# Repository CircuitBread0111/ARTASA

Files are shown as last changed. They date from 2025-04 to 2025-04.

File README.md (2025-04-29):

# ARTASA: Automated Robotic Text And Speech Assistant

**Author:** Jerrin C. Redmon  
**Platform:** Raspberry Pi + ESP32  
**Date:** April 15, 2025  

## 🧾 Abstract 

ARTASA, a handheld robotic vision system, is designed to assist individuals who have difficulty reading due to blindness, dyslexia, or other vision impairments. Many people with these conditions struggle to determine whether an object contains text. ARTASA addresses these challenges by processing the environment, detecting and interpreting text, and then converting it into speech using text-to-speech software.

The system utilizes a dedicated Serial Peripheral Interface (SPI) camera module designed to capture images at an optimal resolution and color balance, ensuring efficient processing by the Optical Character Recognition (OCR) system. A Raspberry Pi is employed as a dedicated computer to manage the overall software, enhancing both the speed and accuracy of the process. The system operates through three primary stages: image acquisition, image and text processing, and audio output. For optimal performance, it identifies text with a confidence level of 75% or higher before reading it aloud.

The simple handheld device makes it easy to automatically scan objects, identify and verbalize text. This allows for a compact and adaptable design that can be deployed in various environments.

### 🔧 ARTASA Hardware Unit
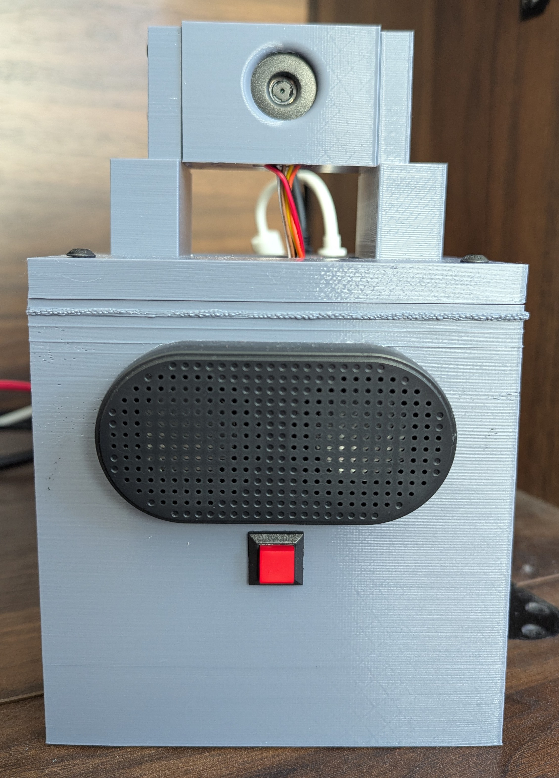
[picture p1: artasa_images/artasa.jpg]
ARTASA Hardware


---
## 📖 Features
- **Button-triggered OCR pipeline**
- **Speech feedback at every stage**
- **On-boot readiness via systemd service**
- **Real-time communication with an ESP32 camera module over UART**

---

## 🧠 Project Structure

| File | Description |
|---|---|
| `artasa.service` | Systemd service to run `artasa_boot.py` on startup |
| `artasa_boot.py` | Startup script that announces readiness and waits for a button press |
| `artasa_main.py` | Main logic: captures image, runs OCR, and speaks the detected text |
| `artasa_camera.ino` | Arduino/ESP32 sketch that captures a JPEG image upon receiving a command |

---

## 🖥️ Software Requirements

- **Python 3.8+**
- **PaddleOCR**
- **OpenCV**
- **Piper TTS** (local text-to-speech engine)
- **gpiozero** (for button input)
- **Systemd** (for auto-start on boot)
- **Arducam_Mega**

Install dependencies with:

```bash
pip install paddleocr opencv-python gpiozero
```

Make sure Piper is installed and accessible at:  
`/home/artasa/.local/bin/piper`

---

## 🔧 Hardware Requirements

- Raspberry Pi (tested on Raspberry Pi 5)
- Arducam Mega 5MP SPI camera module
- Push button wired to **GPIO16**
- Speaker (supports `aplay` for audio output)

---

## 🔁 Boot Flow

1. `artasa.service` triggers `artasa_boot.py` on boot.
2. `artasa_boot.py` plays a startup greeting via Piper.
3. Waits for a button press on GPIO16.
4. When pressed, it runs `artasa_main.py`.

---

## ▶️ Main OCR Flow (`artasa_main.py`)
### 🧠 OCR Text Detection Example
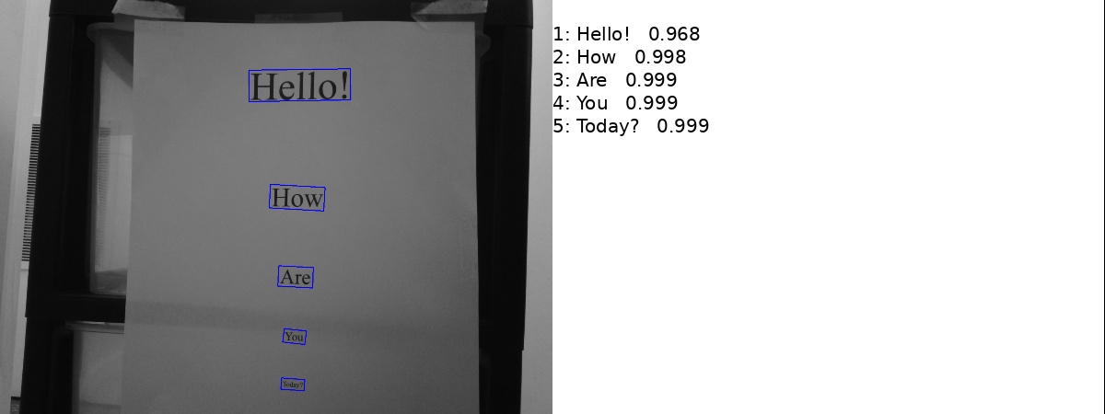
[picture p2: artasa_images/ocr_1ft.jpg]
OCR Output Example


- Sends `"CAP"` to ESP32 via serial (`/dev/ttyUSB0`, 921600 baud).
- Receives a JPEG image over serial (detects SOI `0xFFD8` and EOI `0xFFD9` markers).
- Saves image as `image_output.jpg`.
- Runs PaddleOCR and filters text with confidence > **75%**.
- Saves extracted text to `ocr_output.txt`.
- Uses Piper TTS to read out the result.

---

## 📷 ESP32 Firmware (`artasa_camera.ino`)

- Listens for `"CAP"` command over serial.
- Captures and sends image in JPEG format.
- Appends `"DONE"` to indicate completion.

---

## 🔊 Text-to-Speech Function

Both `artasa_boot.py` and `artasa_main.py` use the `say()` function:

```python
subprocess.Popen([
  "piper", "--model", MODEL_PATH,
  "--config", CONFIG_PATH,
  "--output_file", OUTPUT_WAV
], stdin=subprocess.PIPE)
```

This creates and plays a `.wav` file using `aplay`.

---

## 🧠 Systemd Setup

### 1. Install the Service

```bash
sudo cp artasa.service /etc/systemd/system/
sudo systemctl daemon-reexec
sudo systemctl enable artasa.service
sudo systemctl start artasa.service
```

### 2. File Contents (Excerpt)

```ini
[Unit]
Description=ARTASA Boot Service

[Service]
WorkingDirectory=/home/artasa/Desktop/artasa_master
ExecStart=/usr/bin/env python3 /home/artasa/Desktop/artasa_master/artasa_boot.py
Restart=always
User=artasa
Group=artasa

[Install]
WantedBy=multi-user.target
```

---

## 🚀 Running Manually (Debugging)

If needed, you can run the programs directly:

```bash
python3 artasa_boot.py  # For startup behavior and button handling
python3 artasa_main.py  # To manually run the OCR and speech pipeline
```

---

## 🛠️ Future Improvements

- Add multilingual OCR and speech options.
- Improve serial communication robustness with checksums.
- Add audio feedback for OCR errors or low confidence.

---

### ⚙️ Hardware-Software Interaction Diagram
System Diagram 2

## 📄 License

MIT License.  
Designed and built by **Jerrin C. Redmon**.

---

## 🧠 Acknowledgments

- [PaddleOCR](https://github.com/PaddlePaddle/PaddleOCR)
- [Piper TTS](https://github.com/rhasspy/piper)
- [OpenCV](https://opencv.org/)
- [Arducam](https://github.com/ArduCAM/Arducam_Mega)
- Raspberry Pi + ESP32 communities

---

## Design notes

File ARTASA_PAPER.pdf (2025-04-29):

# Automated Robotic Text and Speech Assistant

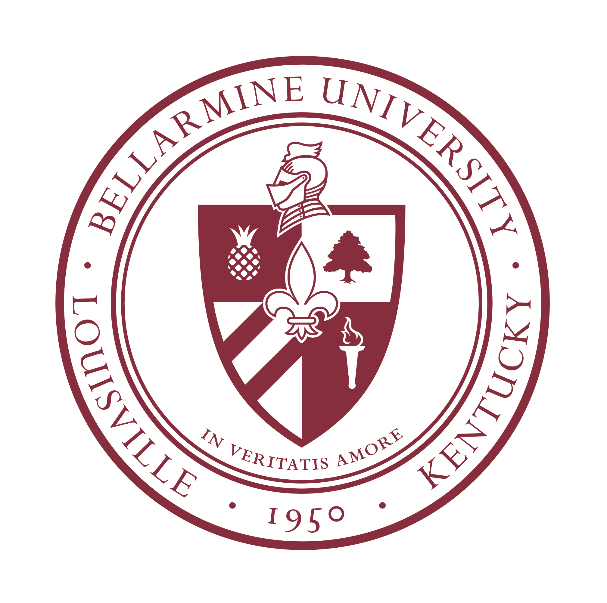
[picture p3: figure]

# Jerrin C. Redmon

# April 29, 2025

Bellarmine University: 2001 Newburg Rd, Louisville, KY 40205

_____________________________________________________________________________________________

ABSTRACT: ARTASA, a handheld robotic vision system, is designed to assist individuals who have difficulty reading due to blindness, dyslexia, or other vision impairments. Many people with these conditions struggle to determine whether an object contains text. ARTASA addresses these challenges by processing the environment, detecting and interpreting text, and then converting it into speech using text-to-speech software. The system utilizes a dedicated Serial Peripheral Interface (SPI) camera module designed to capture images at an optimal resolution and color balance, ensuring efficient processing by the Optical Character Recognition (OCR) system. A Raspberry Pi is employed as a dedicated computer to manage the overall software, enhancing both the speed and accuracy of the process. The system operates through three primary stages: image acquisition, image and text processing, and audio output. For optimal performance, it identifies text with a confidence level of 75% or higher before reading it aloud. The simple handheld device makes it easy to automatically scan objects, identify and verbalize text. This allows for a compact and adaptable design that can be deployed in various environments.

_____________________________________________________________________________________________

### 1. Introduction

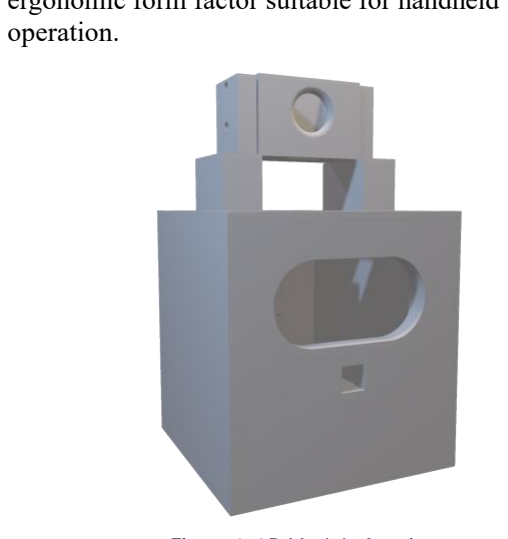
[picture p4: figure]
operation.

Access to printed text remains a significant barrier
for people with visual or cognitive impairments. Traditional assistive tools can be expensive or overly complex, limiting accessibility. ARTASA addresses this by providing an intuitive, embedded system capable of capturing text in real-time and converting it into clear speech output. It simplifies the user interaction to a single button press and automates all backend processes.

### 2. System Overview

The ARTASA system is composed of four primary components that work together to provide real-time text recognition and speech output. At the core of image acquisition is an ESP32 microcontroller paired with an Arducam Mega 5MP camera, which captures images upon button activation. These images are transmitted via serial communication to a Raspberry Pi 5, which handles the processing pipeline. The Raspberry Pi utilizes PaddleOCR, a deep learning-based optical character recognition engine, to extract text from the received images. Once the text is recognized, it is vocalized using Piper TTS, a lightweight, offline-capable text-to-speech engine, enabling immediate auditory feedback to the user.

### 3. Design and Hardware

The hardware configuration of the ARTASA system includes several integrated components designed for efficient image capture and user interaction. At the forefront is the ESP32 module equipped with an Arducam Mega 5MP camera, which serves as the primary imaging device. A tactile button, wired directly to the Raspberry Pi 5 running Pi OS, allows users to manually trigger image capture. Audio output is facilitated by an 8-ohm speaker connected to the Pi, enabling clear verbal feedback. All components are housed within a custom 3D-printed enclosure (see Figure 1), providing a compact and ergonomic form factor suitable for handheld

### 3.1 Software Workflow

The software workflow of the ARTASA system is designed to efficiently process and vocalize textual information from captured images. The sequence begins with a user-initiated trigger event, where a button press activates the system. Upon activation, the ESP32 captures a JPEG image using the Arducam Mega 5MP camera. This image is then transmitted to Raspberry Pi via USB serial communication. Once received, the Raspberry Pi processes the image using PaddleOCR, a deep learning-based engine that extracts text. To ensure reliability, only text with a confidence score of 75% or higher is retained. Finally, the filtered text is vocalized through Piper TTS, which converts the recognized content into speech and outputs it through the connected speaker. A systemd .service file (artasa.service) was configured to run the Python OCR-to-speech script on startup. This ensures ARTASA operates autonomously after power-up.

Figure 1: 3D Model of casing

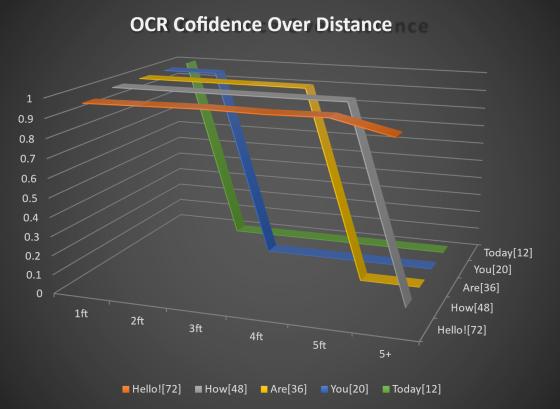
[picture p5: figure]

### 3.2 Electrical Schematic

This schematic, designed in KiCad, demonstrates the physical wiring and logic levels for interfacing the Arducam module with the ESP32 UART pins. It includes decoupling, buzzer output for feedback, and clearly labeled GPIO usage, ensuring repeatable set up.

The full wiring schematic of ARTASA includes:

- An ESP32 wired to an Arducam module and Buzzer
- USB serial communication lines connecting to the Raspberry Pi
- Button connection between Raspberry Pi GPIO pins

### 4. Testing and Results

Testing was conducted using a vertically arranged sentence printed on paper, viewed at increasing distances. Confidence scores from PaddleOCR were recorded, (see Figure 3). OCR Confidence over Distance illustrates the performance and limitations of the ARTASA system’s text recognition capabilities at varying distances. On average, the latency from image capture to speech output is approximately 2.5 seconds. The system is capable of reading fonts as small as 10 points under favorable lighting conditions, maintaining an accuracy range of 85–95% for high-contrast text. The implemented OCR confidence filter effectively eliminates low-quality reads, enhancing the reliability of spoken output. However, system performance diminishes significantly at distances beyond four feet. Additionally, motion blur and suboptimal lighting conditions adversely affect OCR confidence, underscoring the importance of stable positioning and adequate illumination during use.

### 5. Conclusion and Future Work

ARTASA successfully demonstrates a functional, self-contained assistive reading system for visually impaired users. Its offline operation, simple interface, and modular architecture make it a compelling tool for real-world use. Future enhancements could include:

- Adding feedback to indicate OCR success/failure
- Incorporating translation support
- Deploying a higher-resolution camera module
- Building a custom ergonomic enclosure with tactile feedback

References

[1] PaddleOCR, PaddleOCR: Optical Character Recognition with PaddlePaddle. [Online]. Available: https://github.com/PaddlePaddle/PaddleOCR
[2] Piper TTS, Piper: A fast, local neural text-tospeech system. [Online]. Available: https://github.com/rhasspy/piper
[3] Espressif Systems, ESP32-S3-DevKitC Hardware Reference. [Online]. Available: https://docs.espressif.com/projects/espidf/en/latest/esp32/api-reference/index.html (https://docs.espressif.com/projects/esp-idf/en/latest/esp32/api-reference/index.html)
[4] Arducam, Arducam Mega 5MP OV5642 SPI Camera Module for Any Microcontroller. [Online]. Available: https://docs.arducam.com/Arduino-SPIcamera/MEGA-SPI/MEGA-SPI-Camera/ (https://docs.arducam.com/Arduino-SPI-camera/MEGA-SPI/MEGA-SPI-Camera/)

Figure 3: Graph of OCR Confidence

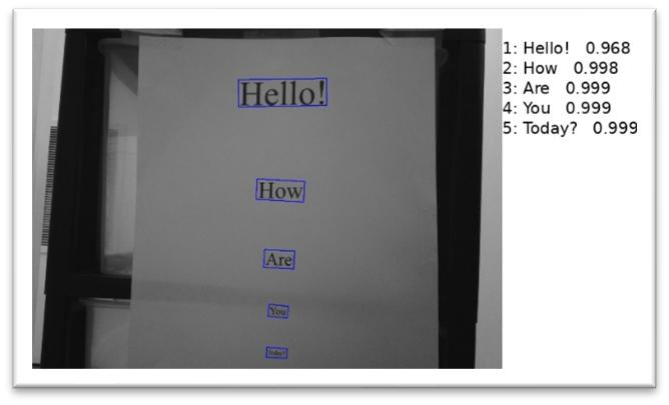
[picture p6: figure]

Figure 2: Image of OCR output

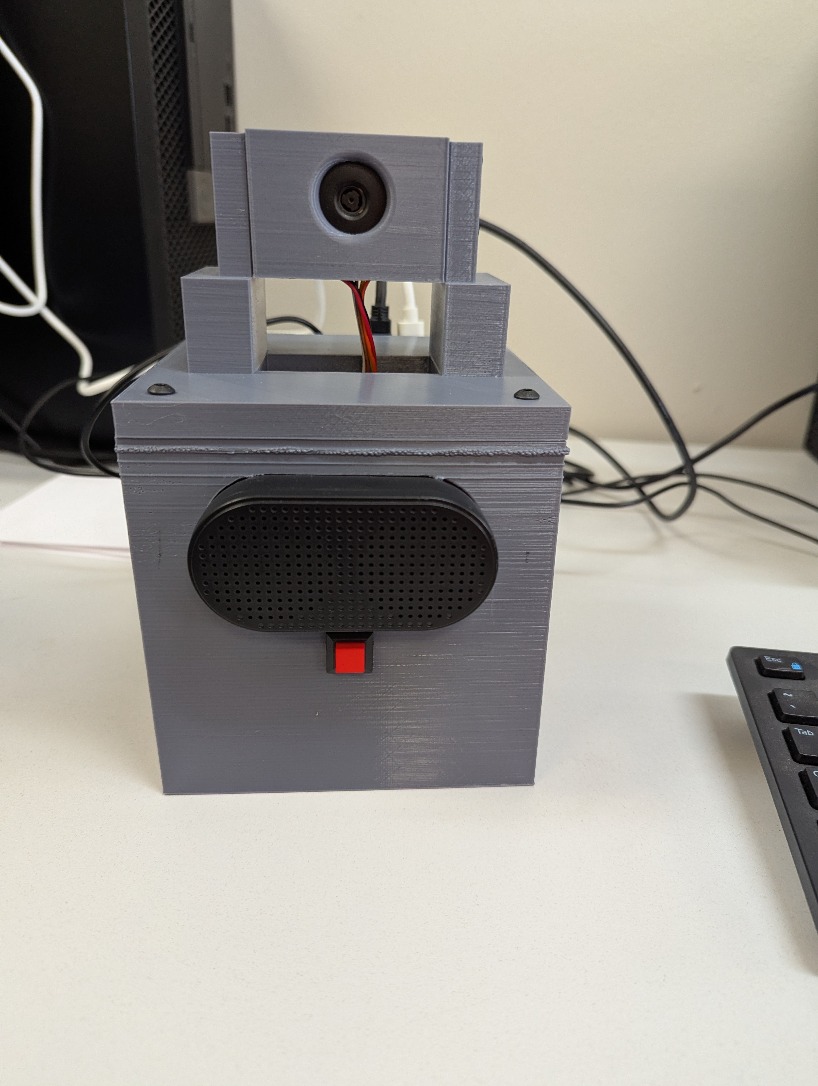
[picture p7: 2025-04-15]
artasa_images/artasa2.jpg

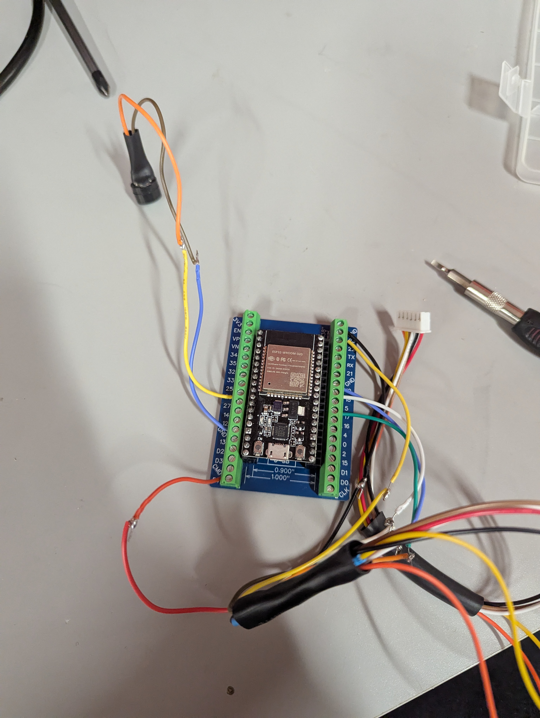
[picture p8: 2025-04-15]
artasa_images/image_mcu.jpg

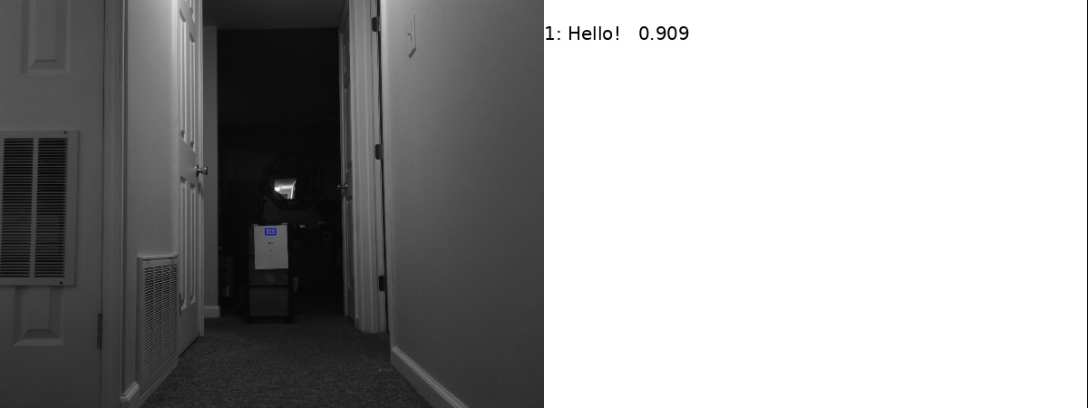
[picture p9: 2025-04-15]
artasa_images/ocr_5ft+.jpg

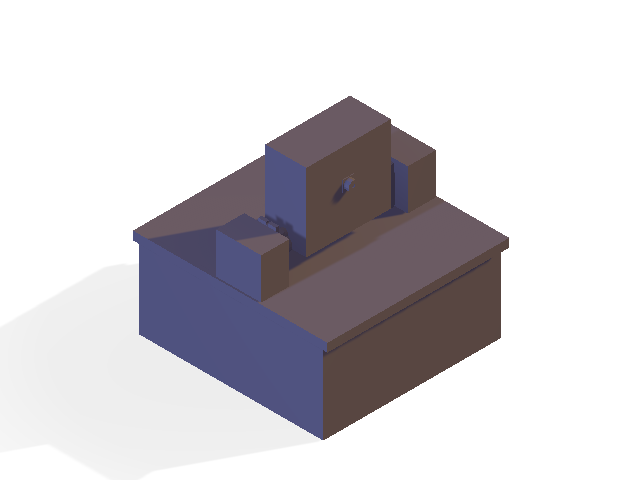
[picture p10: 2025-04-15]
artasa_images/ARTASA_Model_A.png

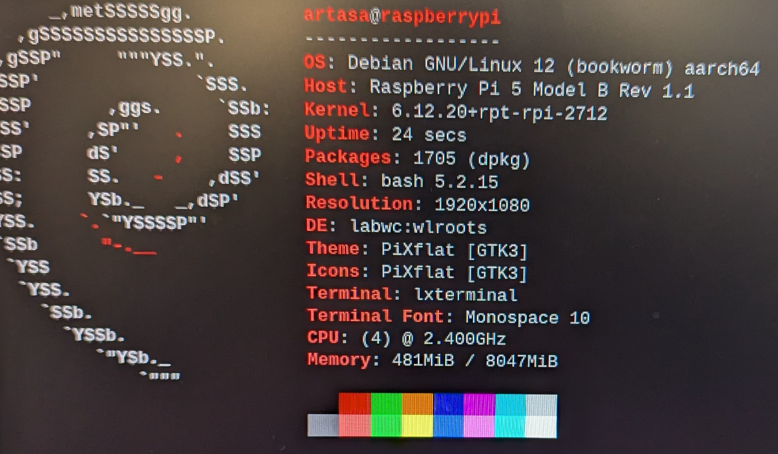
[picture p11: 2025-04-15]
artasa_images/neofetch.jpg

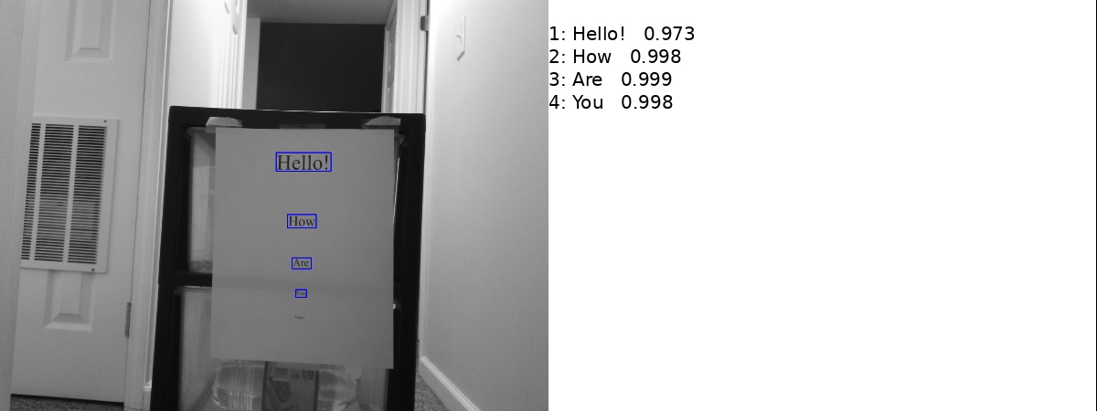
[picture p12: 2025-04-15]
artasa_images/ocr_2ft.jpg

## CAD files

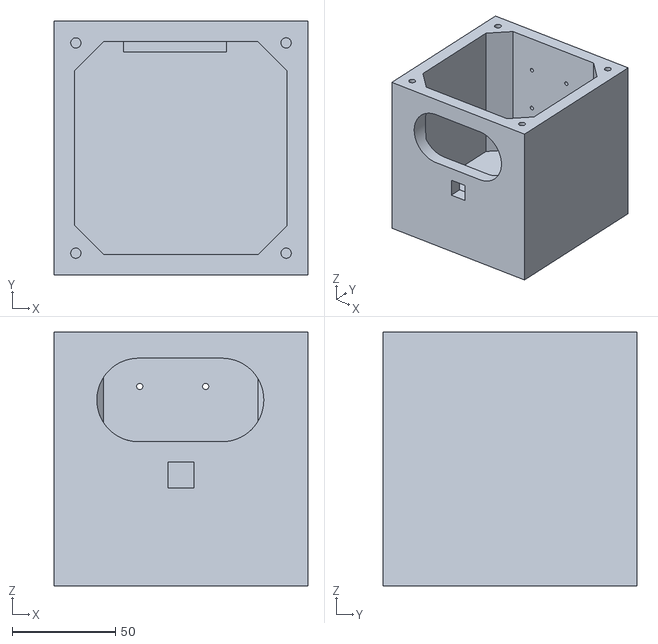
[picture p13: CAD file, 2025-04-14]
artasa_models/BOX.stl
123.3 x 123.3 x 123.3

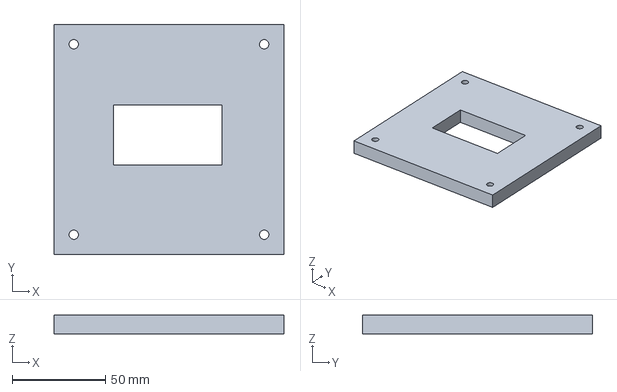
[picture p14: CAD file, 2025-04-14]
artasa_models/CAD_files/top.FCStd
123.3 x 123.3 x 10.0 mm

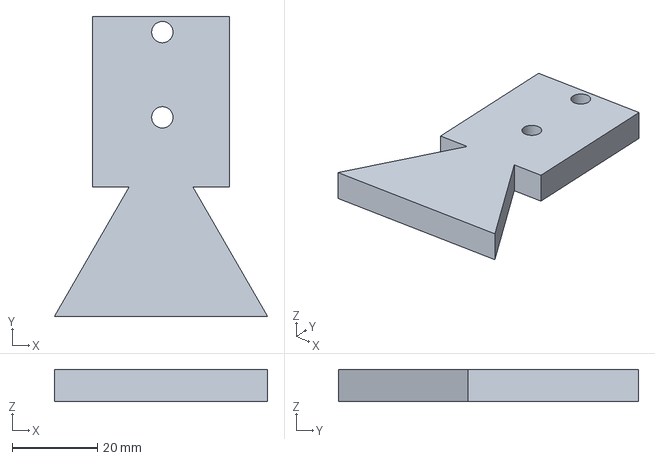
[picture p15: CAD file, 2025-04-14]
artasa_models/CAD_files/Camera_Bracket.FCStd
50.0 x 70.3 x 7.50 mm

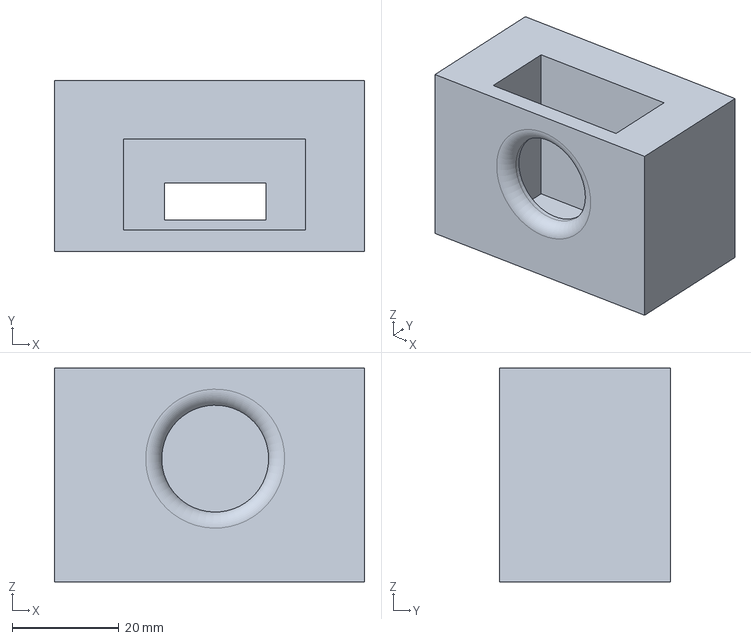
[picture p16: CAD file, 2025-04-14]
artasa_models/CAD_files/Camera_Base.FCStd
58.0 x 32.0 x 40.0 mm

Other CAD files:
artasa_models/CAD_files/body.FCStd
artasa_models/Camera_Base.stl
artasa_models/Top.stl

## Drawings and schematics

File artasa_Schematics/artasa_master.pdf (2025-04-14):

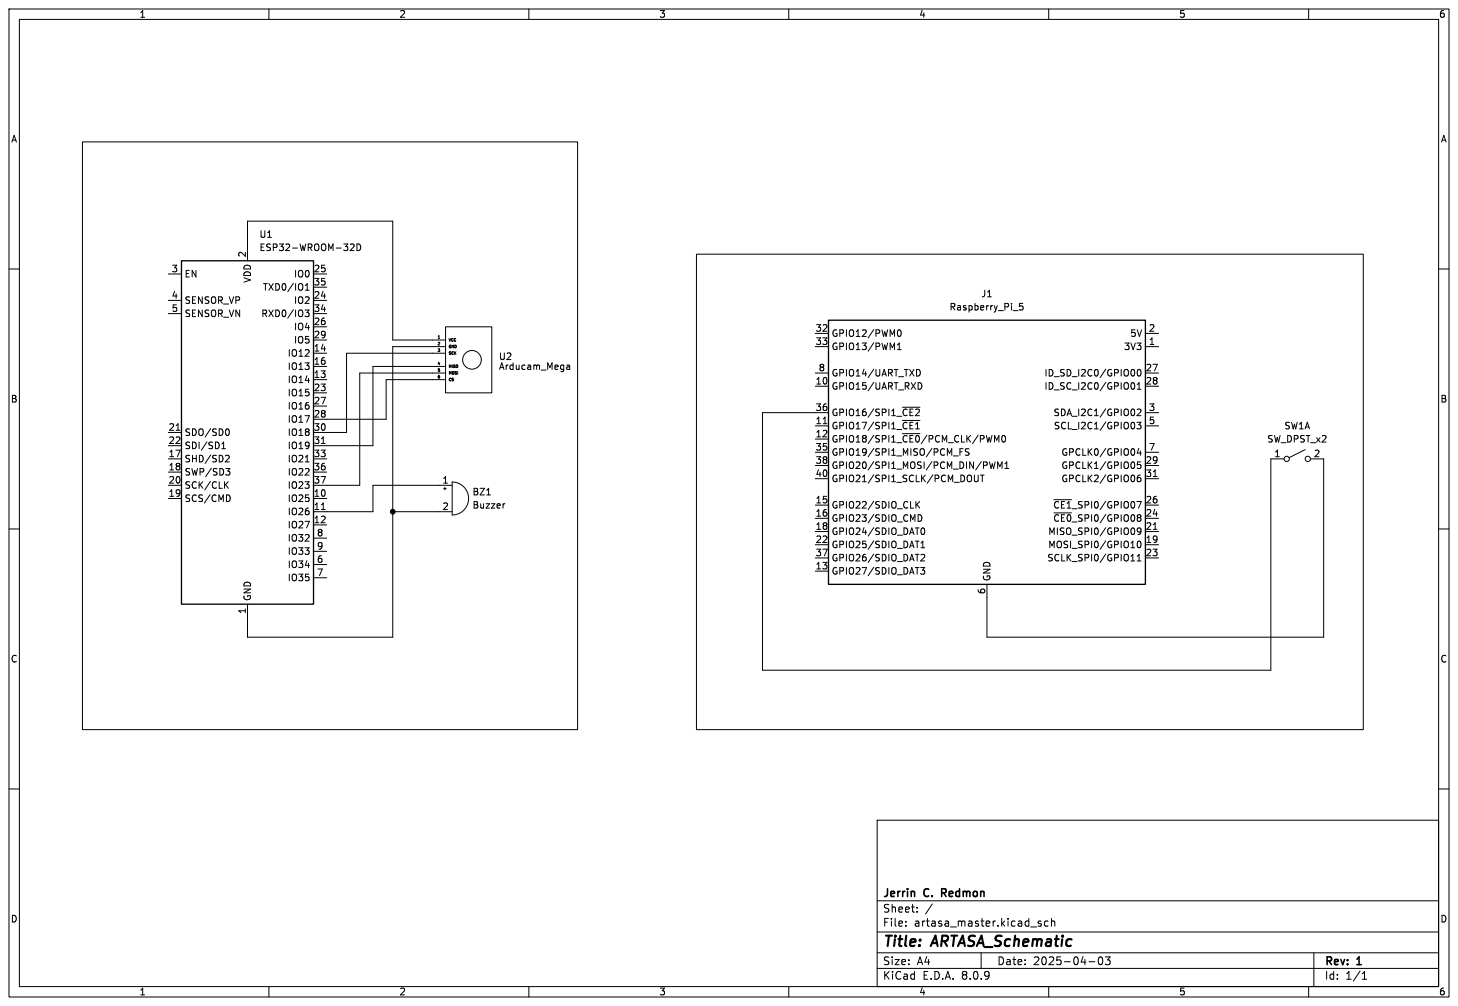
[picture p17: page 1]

2 SCK/CLK 20 SDO/SD0 21 SDI/SD1 22

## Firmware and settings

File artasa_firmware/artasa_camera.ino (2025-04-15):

///////////////////////////|
//|File: artasa_camera.ino
//|Author: Jerrin C. Redmon
//|Language: C++
//|Version: 1.1.2 
//|Date: April 15, 2025
///////////////////////////|

/*
 * Description:
 * ARTASA Firmware
 * This firmware is designed to work with the Arducam Mega 5MP 
 * camera module. It captures images and sends them over serial 
 * to a connected device. Includes a buzzer that provides an audio 
 * cue when a picture is taken.The camera settings are configured 
 * for optimal performance for OCR. Designed to be used 
 * with the ESP32 microcontroller.
 */

//----------------------------------------------------------------

// Includes //
#include "Arducam_Mega.h"                                           // Arducam Camera Library

// Defines //
#define BUZZER 26                                                   // Buzzer Pin
#define FREQUENCY 2000                                              // PWM Frequency in Hz
#define RESOLUTION 8                                                // 8-bit resolution (0-255)
#define VOLUME 128                                                  // 8-bit Volume Control (0-255)
#define CS 17                                                       // Arducam Chip Select Pin

// Arducam//
Arducam_Mega Camera(CS);                                            // Create Camera Object

// Camera Settings //
CAM_IMAGE_MODE resolution = CAM_IMAGE_MODE_UXGA;                    // 1600x1200
CAM_IMAGE_PIX_FMT format = CAM_IMAGE_PIX_FMT_JPG;                   // JPEG Format

// Image Buffer //
const size_t buffer_size =0xff;                                     // 255 Hex
uint8_t image_buffer[buffer_size] = { 0 };                          // Image Buffer

// Setup //
void setup() {                                                         

  Serial.begin(921600);                                             // Set serial Baudrate to 921600
  delay(2000);                                                      // Delay for esp32 to begin serial
  ledcAttach(BUZZER, FREQUENCY, RESOLUTION);                        // Set Buzzer PWM Pin
  Camera.begin();                                                   // Initalize Camera
}

// Buzzer //
void buzzer(int t) {

  for (int i = 0; i < t; i++) {
    ledcWrite(BUZZER, VOLUME);                                      // Set Volume
    delay(150);                                                     // Sound Duration
    ledcWrite(BUZZER, 0);                                           // Turn off Buzzer       
    delay(150);                                                     // Delay between sounds   
  }
}

// Capture //
void capture() {

  buzzer(1);                                                        // Audio cue for taking a picture
  Camera.setAutoISOSensitive(0);                                    // Set Camera ISO to AUTO
  Camera.setAutoExposure(0);                                        // Set Camera Exposure to AUTO
  Camera.setAutoFocus(0);                                           // Set Camera Focus to AUTO 
  Camera.setColorEffect(CAM_COLOR_FX_BW);                           // B/W for increased legibility
  Camera.takePicture(resolution, format);                           // Takes a picture
  size_t image_size = Camera.getTotalLength();                      // Get image size 
  size_t bytes_read = 0;                                            // Total bytes read

  while (bytes_read < image_size) {                                 // Writing Image Over Serial
    size_t chunk_size = min(buffer_size, image_size - bytes_read);  // Read in chunks
    Camera.readBuff(image_buffer, chunk_size);                      // Read image data into buffer   
    Serial.write(image_buffer, chunk_size);                         // Write image data to serial 
    bytes_read += chunk_size;                                       // Increment bytes read
    delay(1);                                                       // Delay to prevent buffer overflow     
          
  }

  buzzer(2);                                                        // Audio cue for completion 
  Serial.println("DONE");                                           // Image transfer complete                                                 
}

// Loop //
void loop() {

  if (Serial.available()) {                                         // Check if serial is available
    
    String cmd = Serial.readStringUntil('\n');                      // New line character termination
    cmd.trim();                                                     // Remove whitespace
         
    if (cmd.equalsIgnoreCase("CAP")) {                              // Check for command 
      capture();                                                    // Capture image
    }

    else {                
      Serial.println("Unkown Command");                             // Command Unrecognized Error      
    }
  }
}

// EOF //

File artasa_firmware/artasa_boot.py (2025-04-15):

#!/usr/bin/env python3
#//////////////////////////
#|File: artasa_boot.py
#|Author: Jerrin C. Redmon
#|Version: 1.1.1
#|Date: April 15, 2025
#//////////////////////////

# Description #
# A python script to prepare artasa for booting. This script
# provides an audible text-to-speech that is
# has been booted sucessfully and prepares a push button to
# start the main program.

#-----------------------------------------------------------------

# Imports #
import time                                                                                                                     # Import time for sleep and delay functions
import subprocess                                                                                                               # Import subprocess for running shell commands                        
from gpiozero import Button                                                                                                     # GPIO library for button handling                               
from signal import pause                                                                                                        # Signal library for pausing the program

# File Paths #
MODEL_PATH = "/home/artasa/piper_models/en_US/en_US-joe-medium.onnx"                                                            # Path to the model (Joe)
CONFIG_PATH = "/home/artasa/piper_models/en_US/en_US-joe-medium.onnx.json"                                                      # Path to the config file
OUTPUT_WAV = "artasa_tts.wav"                                                                                                   # Output wav file name

# Button Setup #
BUTTON_PIN = 16                                                                                                                 # GPIO pin number for the button       
button = Button(BUTTON_PIN, pull_up=True, bounce_time=0.3)                                                                      # Button setup with pull-up resistor and debounce time
last_pressed = 0                                                                                                                # Last button press time                                
cooldown = 5                                                                                                                    # Cooldown between button presses (seconds)


# Say #
def say(text):                                                                                                                  # Function to convert text to speech using Piper TTS engine

    try:
        p1 = subprocess.Popen(                                                                                                                         
            ["/home/artasa/.local/bin/piper", "--model", MODEL_PATH, "--config", CONFIG_PATH, "--output_file", OUTPUT_WAV],                                                
            stdin=subprocess.PIPE)                                                                                              # Popen to run piper with the model and config file                                                                                                                
        p1.communicate(input=text.encode("utf-8"))                                                                              # Send text to piper                                           
        subprocess.run(["aplay", OUTPUT_WAV])                                                                                   # Play the output wav file using aplay
                                                             
    except Exception as e:                                                                                                      # Exception handling for subprocess errors
        print(f"Error running piper: {e}")                                                                                      # Print error message if subprocess fails                    


# Boot Sequence #
say("Boot successful!")                                                                                                         # Print boot message
say("My name is ARTASA, your automated robotic text and speech assistant.")                                                     # Print name message                      
say("Please press the button to start the main program.")                                                                       # Print button message
                 
                     
# Button Handler #
def Button_Handler():                                                                                                           # Button handler function

    global last_pressed                                                                                                         # Access the global variable last_pressed
    now = time.time()                                                                                                           # Get the current time                                           
                                                                       
    if (now - last_pressed >= cooldown):                                                                                        # Check if the cooldown period has passed   
        say("Please show item to me.")                                                                                          # Print item message                          

        try:
            subprocess.run(["python3", "/home/artasa/Desktop/artasa_master/artasa_main.py"])                                    # Run the main program script

        except Exception as e:   
            print(f"Error running script: {e}")                                                                                 # Print error message if script fails

        last_pressed = now                                                                                                      # Update last_pressed to current time                                    

    else:                                                                                          
        print("Ignored press due to cooldown")                                                                                  # Print ignored message if button press is within cooldown period


# Button Lisenser #
button.when_pressed = Button_Handler                                                                                            # Assign the button handler 
print("Waiting for button press...")                                                                                            # Print waiting message
pause()                                                                                                                         # Pause the program

# EOF #                                          

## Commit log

2025-03-24 added camera debugger
2025-04-14 Added Models
    [BOX.stl, Camera_Base.FCStd, Camera_Base.stl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]
2025-04-14 added schematics
    [artasa_master.kicad_pcb, artasa_master.kicad_sch]
